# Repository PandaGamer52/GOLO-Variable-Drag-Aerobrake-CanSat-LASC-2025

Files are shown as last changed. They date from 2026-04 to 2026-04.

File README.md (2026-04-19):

GOLO - Variable Drag Aerobrake CanSat 🛰️
Este repositorio contiene el código fuente, los esquemáticos electrónicos y los modelos mecánicos de GOLO, un satélite autónomo (CanSat) de caída libre diseñado para realizar experimentos aerodinámicos durante su descenso.


Este proyecto fue desplegado exitosamente en el Latin American Space Challenge (LASC) 2025, logrando el 5º lugar general.

🚀 Resumen del Proyecto
GOLO es una sonda cilíndrica de 80 mm de diámetro por 300 mm de longitud, con una masa total de 750 gramos. Su objetivo principal es demostrar una desaceleración controlada mediante un aerofreno de arrastre variable, al mismo tiempo que recopila y transmite datos atmosféricos en tiempo real.

⚙️ Mecanismo de Aerofrenado
El sistema transforma el movimiento lineal en una expansión radial controlada:

Actuación Principal: Utiliza un motor DC acoplado a un tornillo de avance infinito.

Cinemática: El tornillo desplaza una placa base conectada a un mecanismo de cuatro barras.

Despliegue: El movimiento empuja brazos articulados hacia el exterior, desplegando el dosel para aumentar la resistencia aerodinámica y reducir la velocidad de descenso a ~20 m/s.

💻 Aviónica y Computadora de Vuelo (Helios PCB)
La sonda opera de manera completamente independiente de la aviónica principal del cohete.

Microcontrolador: Teensy 4.1.

Sensores: IMU MPU6050 y sensor ambiental BME280 (presión y temperatura).

Telemetría: Módulo LoRa RA-02 independiente para transmisión a la estación terrena.

Almacenamiento: Registro redundante en tarjeta microSD a bordo.

📡 Estación Terrena
La comunicación se mantiene mediante una interfaz gráfica de usuario (GUI) personalizada desarrollada en MATLAB y JavaScript. Permite:

Visualización en tiempo real de altitud, velocidad, coordenadas GPS y orientación.

Generación de gráficos y registro de datos para análisis post-vuelo.

🗺️ Perfil de Misión (CONOPS)
Despliegue (~1000m AGL): Expulsión del cohete y despliegue del paracaídas de drogue (descenso a 15 m/s).

Activación del Aerofreno (~500m AGL): Liberación de la cápsula y expansión del mecanismo de arrastre variable (descenso a 20 m/s).

Recuperación (~200m AGL): Eyección del aerofreno y despliegue del paracaídas principal para un aterrizaje seguro a 5-6 m/s.

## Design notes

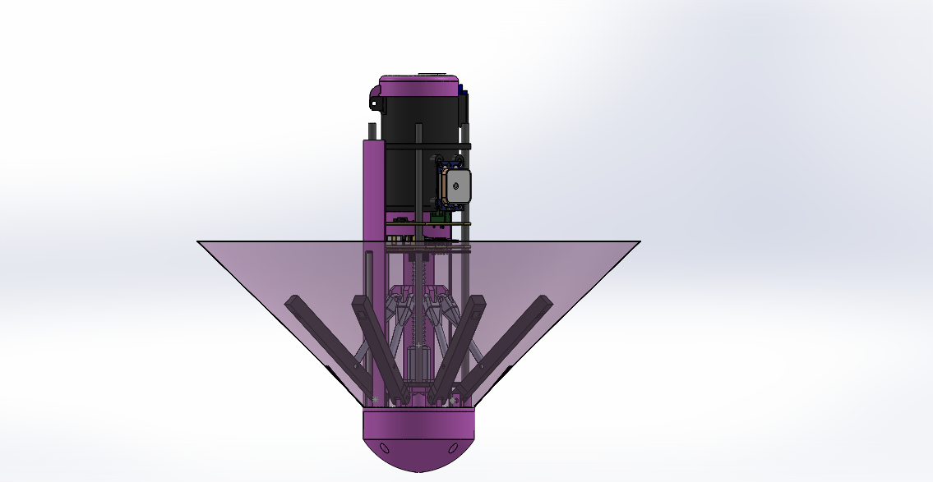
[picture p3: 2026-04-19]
CANSAT_G2.PNG

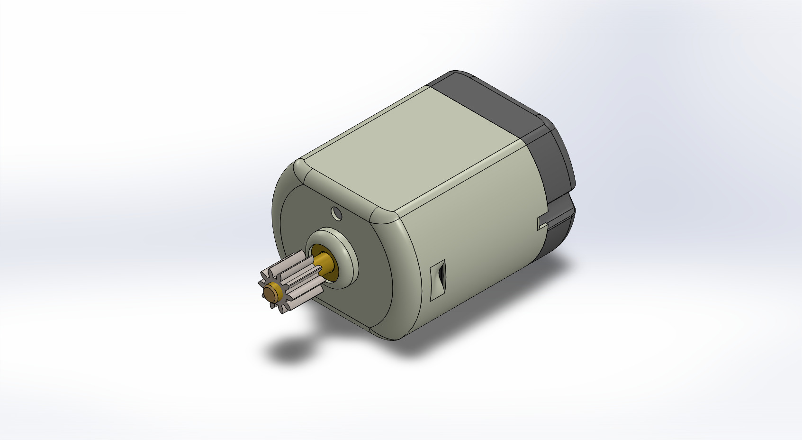
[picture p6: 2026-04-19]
Extras/DC Motor.JPG

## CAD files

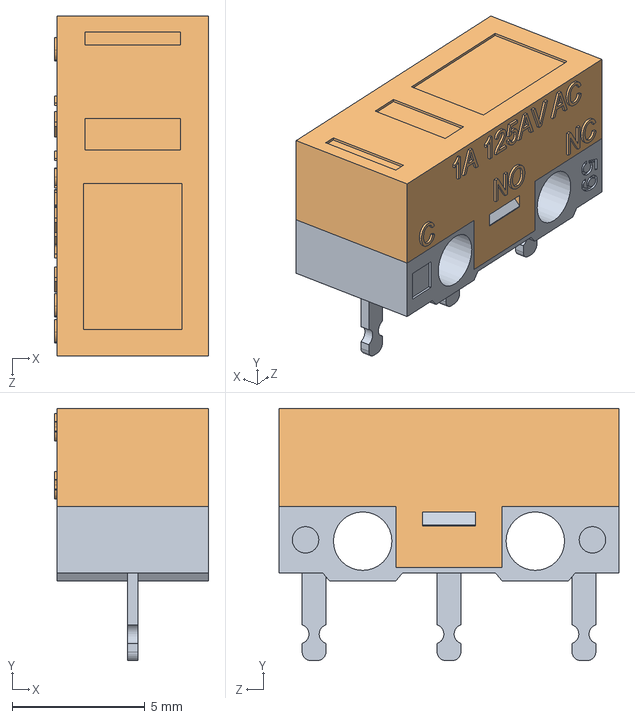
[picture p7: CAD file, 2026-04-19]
Extras/DM1_Series_Switch/DM1_Assembly.SLDASM
5.80 x 9.50 x 12.8 mm
Low_Part
High_Part

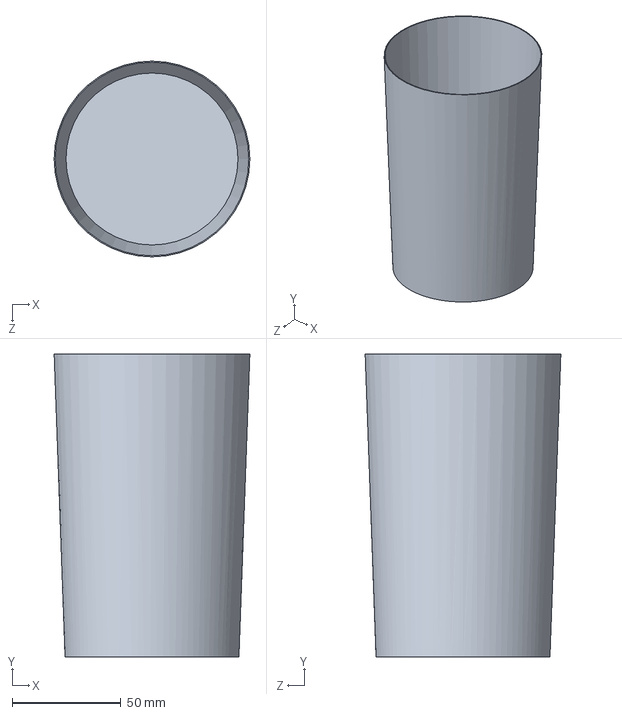
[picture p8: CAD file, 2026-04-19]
Aerofreno0.SLDPRT
90.0 x 139.3 x 90.0 mm

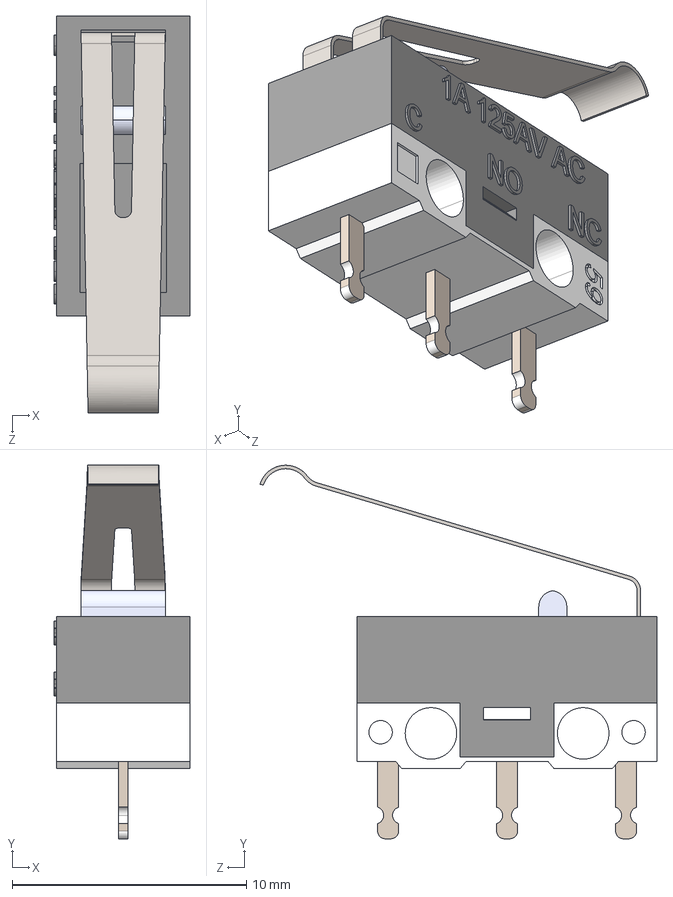
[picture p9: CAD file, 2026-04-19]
Extras/DM1_Series_Switch/STEP/DM1-02P-30-3.STEP
5.80 x 15.9 x 16.9 mm
Low_Part
High_Part
Button
Hook_Lever

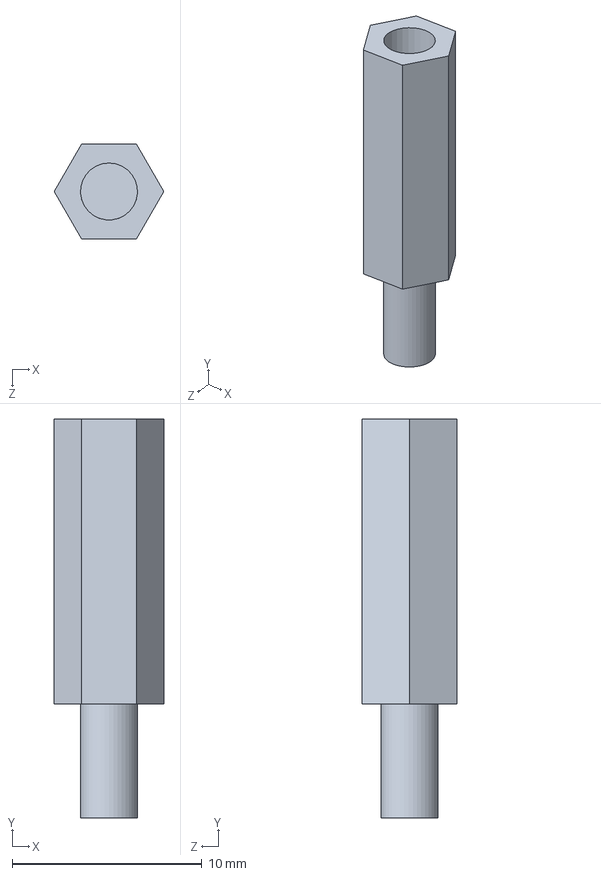
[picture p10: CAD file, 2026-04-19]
Extras/Piezas/Separador laton H-M M3x15x6mm.SLDPRT
5.77 x 21.0 x 5.00 mm

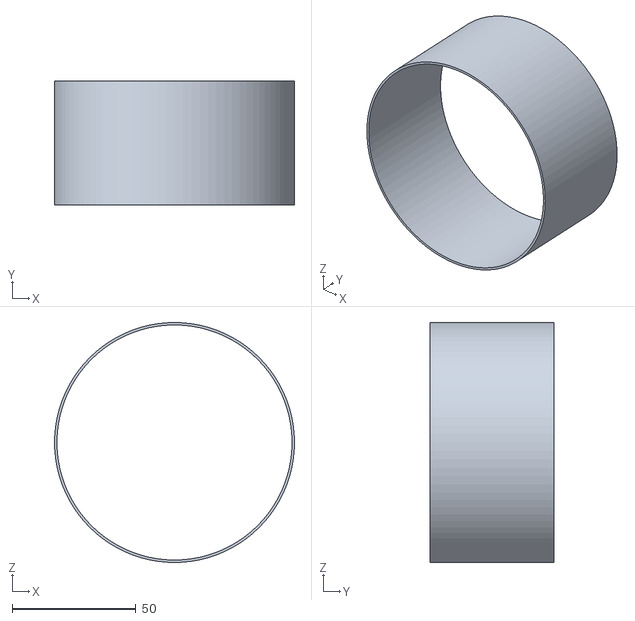
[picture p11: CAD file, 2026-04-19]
STL/envol_test.STL
97.0 x 50.0 x 97.0

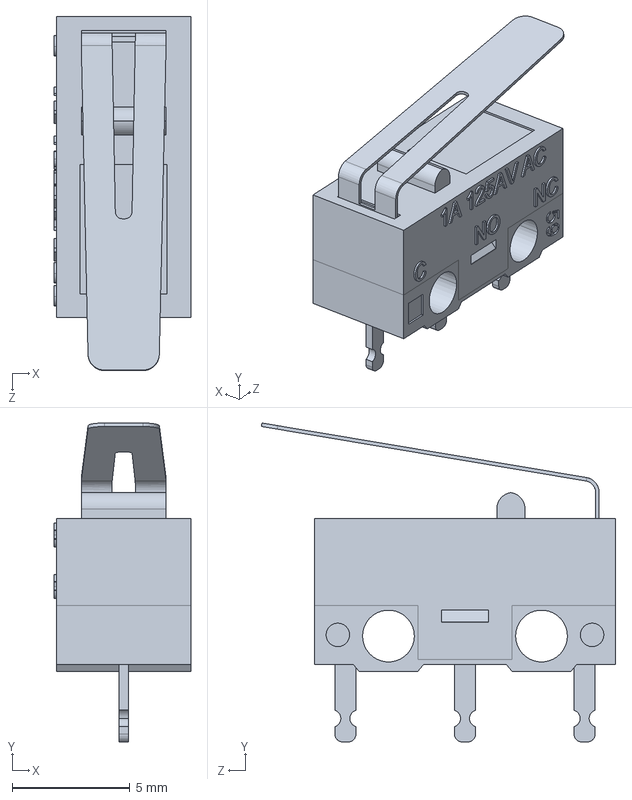
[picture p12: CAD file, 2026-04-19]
Extras/DM1-01P-30-3.SLDPRT
5.80 x 13.5 x 15.1 mm

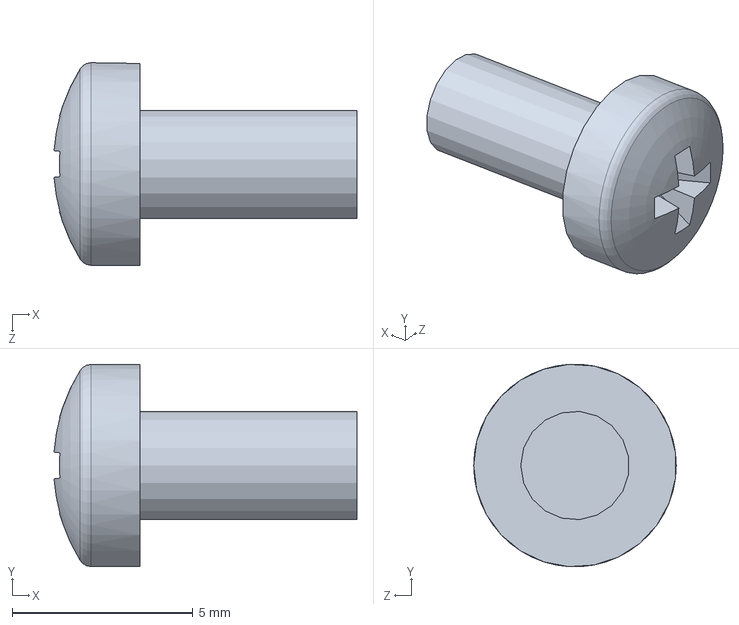
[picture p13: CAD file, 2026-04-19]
Extras/Piezas/Tornillo acero M3x6mm.SLDPRT
8.37 x 5.59 x 5.60 mm

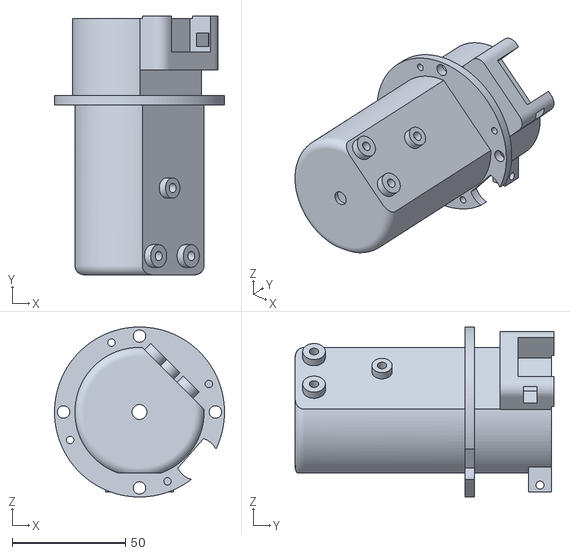
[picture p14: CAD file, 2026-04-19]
STL/TANQUE - Base_top-1-1.STL
75.0 x 114.1 x 75.0

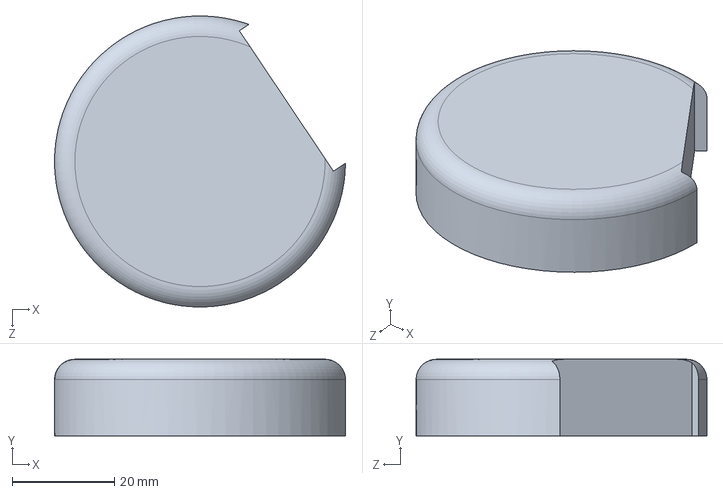
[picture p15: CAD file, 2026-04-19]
Top_tapa.SLDPRT
57.0 x 15.0 x 57.0 mm

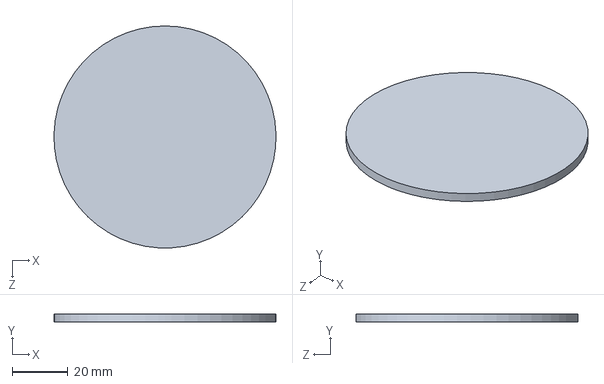
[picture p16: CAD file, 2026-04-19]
Base_EJE.SLDPRT
80.0 x 3.00 x 80.0 mm

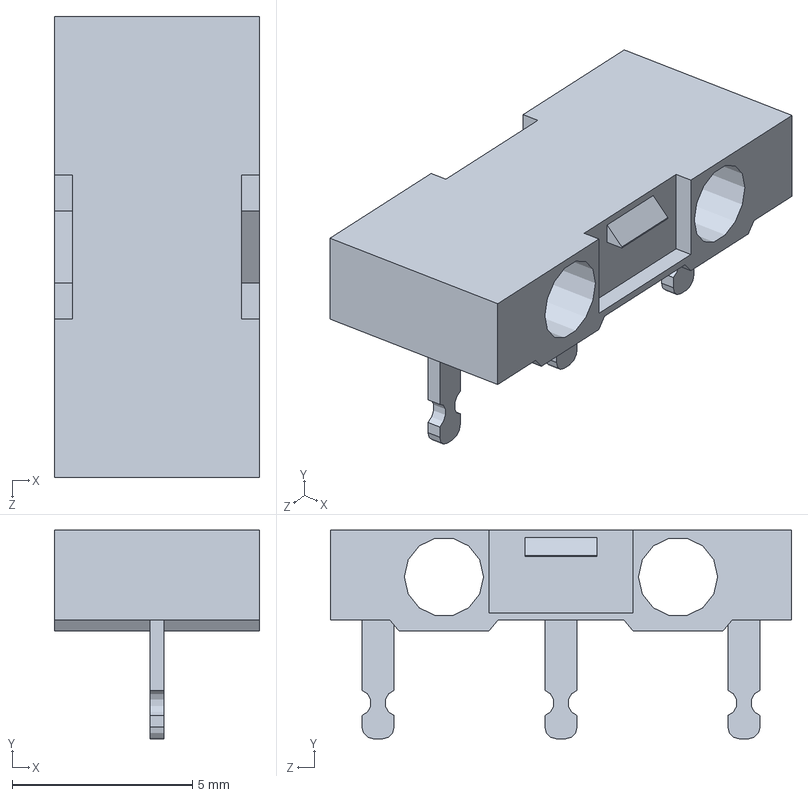
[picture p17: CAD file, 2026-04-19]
Extras/DM1_Series_Switch/Low_Part.SLDPRT
5.70 x 5.80 x 12.8 mm

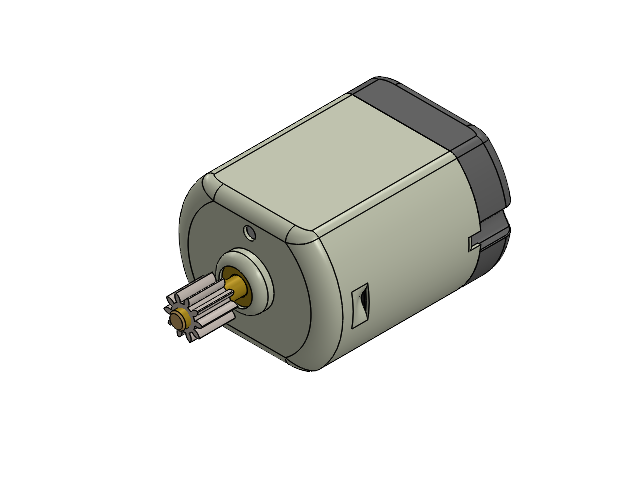
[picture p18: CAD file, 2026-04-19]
Extras/DC Motor.SLDASM
Cover
Brushing1
End Contact x 2
Housing
Magnet x 2
Spacer
Brushing2 shaft fixture
Rotor
spur gear_am

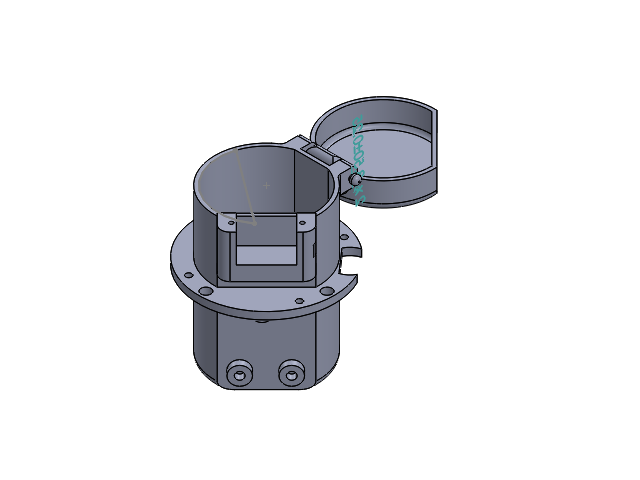
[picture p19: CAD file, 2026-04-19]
TANQUE.SLDASM
Base_top
Top_tapa
PERNOO2

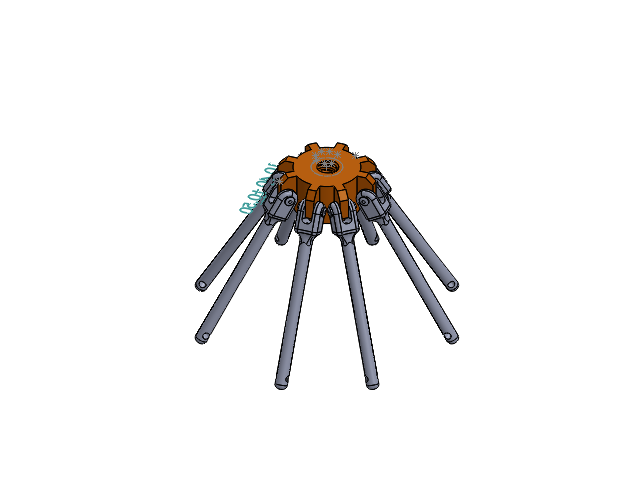
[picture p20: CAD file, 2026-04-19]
Base_brazos_artic.SLDASM
Base_brazos
Brazo_artic x 8
PERNO_3.4 x 8

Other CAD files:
CANSAT_G2.SLDASM
Extras/DM1_Series_Switch/High_Part.SLDPRT
Extras/DM1_Series_Switch/Hook_Lever.SLDPRT
Extras/DM1_Series_Switch/STEP/DM1-01P-30-3.STEP
3D_PCB_CARGA-UTIL_3_2025-09-20.SLDPRT
Acople_B.SLDPRT
Aerofreno.SLDPRT
Arco.SLDPRT
Base_brazos.SLDPRT
Base_brazos_artic.SLDPRT
Base_motor.SLDPRT
Base_top.SLDPRT
Bay_base2_Barrenos_acople.SLDPRT
Brazo.SLDPRT
Brazo_artic.SLDPRT
Eje.SLDPRT
Envol.SLDPRT
Extras/Bornera doble.SLDPRT
Extras/Bornera doble.STEP
Extras/Brushed DC Motor v8.SLDPRT
Extras/Brushed DC Motor v8.step
Extras/Brushed DC Motor v8.stl
Extras/DC Motor.SLDPRT
Extras/DM1_Series_Switch/Button.SLDPRT
Extras/DM1_Series_Switch/Long_Lever.SLDPRT
Extras/DM1_Series_Switch/STEP/DM1-00P-110-3.STEP
Extras/DM1_Series_Switch/STEP/DM1-03P-30-3.STEP
Extras/DM1_Series_Switch/Short_Lever.SLDPRT
Extras/GY-NEO6MV2-withAnt v2.SLDPRT
Extras/GY-NEO6MV2-withAnt v2.step
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

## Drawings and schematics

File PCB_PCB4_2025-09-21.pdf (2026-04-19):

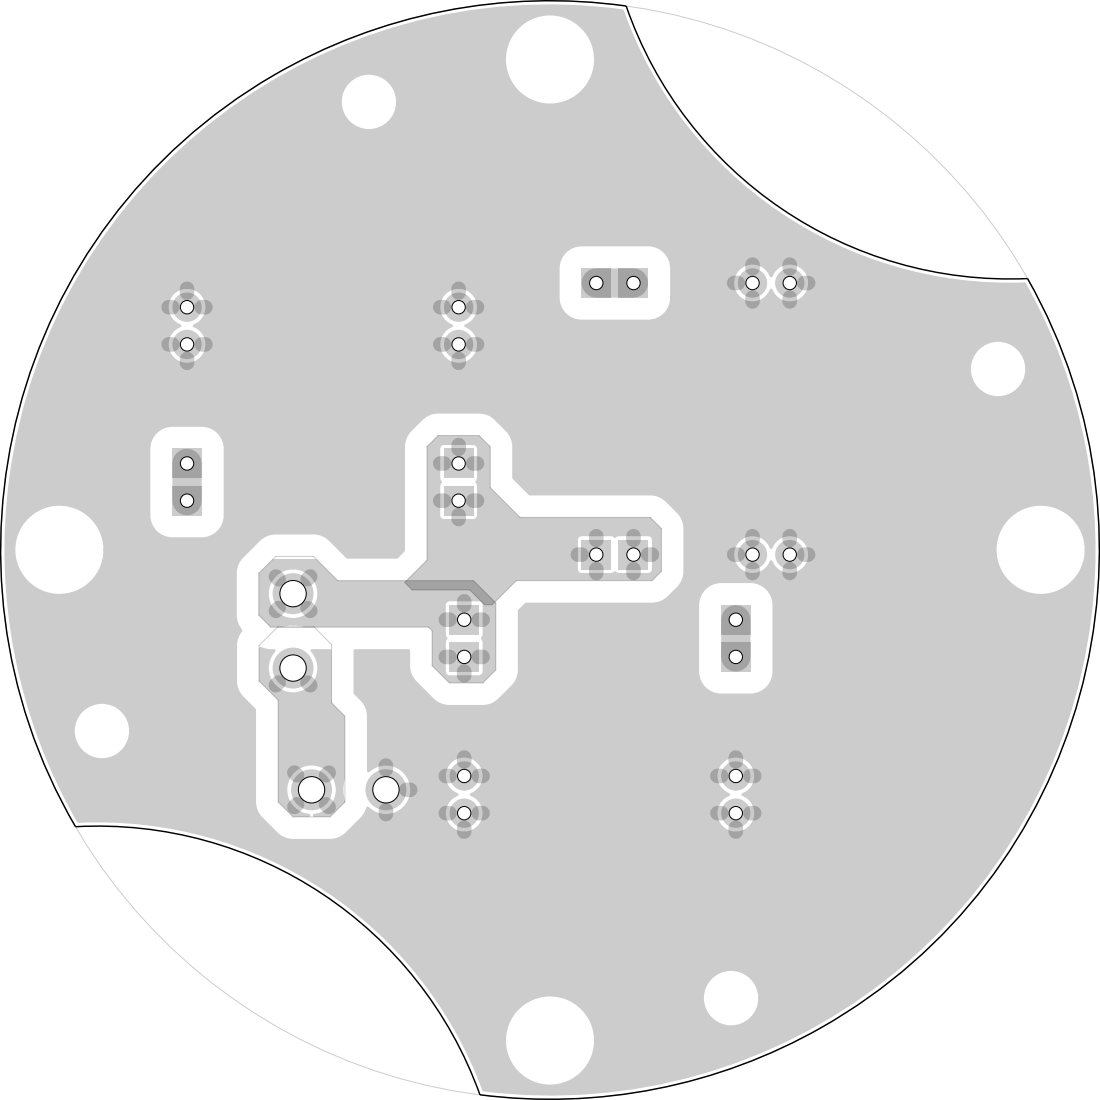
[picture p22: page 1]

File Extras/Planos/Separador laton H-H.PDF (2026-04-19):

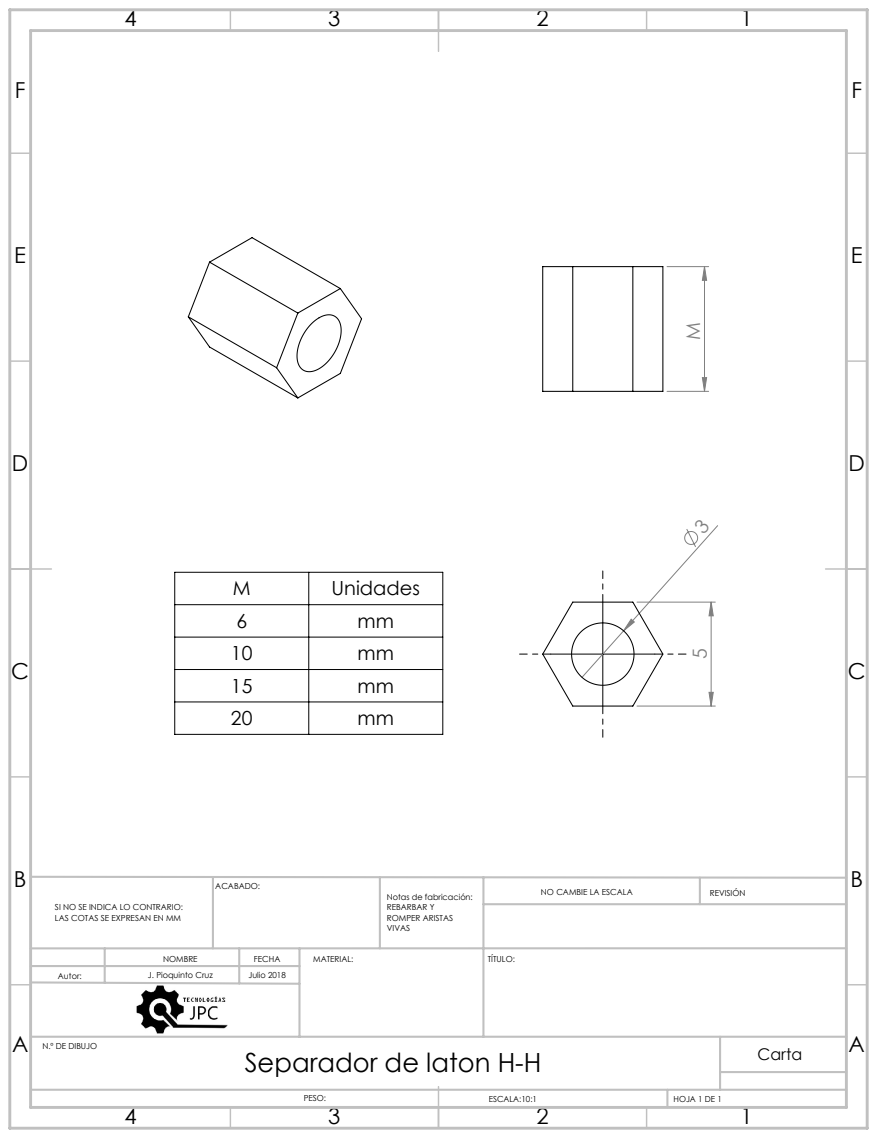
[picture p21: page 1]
NO CAMBIE LA ESCALA; REVISIÓN; N.º DE DIBUJO; ESCALA:10:1; HOJA 1 DE 1

M | Unidades
6 | mm
10 | mm
15 | mm
20 | mm

Notas de fabricación:
REBARBAR Y
ROMPER ARISTAS
VIVAS

SI NO SE INDICA LO CONTRARIO:
LAS COTAS SE EXPRESAN EN MM

NOMBRE | FECHA | MATERIAL: | TÍTULO:

Autor: | J. Pioquinto Cruz | Julio 2018

Separador de laton H-H
